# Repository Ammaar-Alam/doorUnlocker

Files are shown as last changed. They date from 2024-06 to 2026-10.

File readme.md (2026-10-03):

# Door Opener

A gearmotor, a printed spindle, and a length of fishing line turn a regular door handle into one you can open from your phone. The website shows the mechanism in 3D, with live controller status and parts you can explore.

[Open the website](https://door.ammaaralam.com) · [Watch the demo](https://youtube.com/shorts/K_ev5bF7mhw)

<a href="https://youtube.com/shorts/K_ev5bF7mhw">Watch the door opener in action on YouTube</a>

## The mechanism

The motor winds fishing line onto a custom spool to pull the handle down. Reversing the motor lets the handle return. An arbor knot anchors the line to the spindle; a round turn and half hitches attach it to the handle, secured under duct tape. The assembly mounts to the door with adhesive strips.

| Part | Purpose |
| --- | --- |
| Arduino Nano ESP32 | Receives commands over Wi-Fi and times each stroke |
| L298N driver | Controls motor direction and speed |
| BRINGSMART 24 V worm gearmotor | Winds and releases the line |
| Printed spindle and base | Gather the line and hold the assembly together |
| Mini breadboard and jumpers | Connect the controller and driver |
| Fishing line, duct tape, mounting strips | Attach the mechanism to the handle and door |

The [hardware guide](hardware/README.md) has part links and print files, including the original spindle STL. The [firmware guide](firmware/README.md) covers wiring, Arduino Cloud setup, uploading, and calibration.

## Try the interface

Use Node.js 22 and npm. No board or credentials are needed for the preview.

```sh
npm ci
npm run preview
```

Open [localhost:3107](http://localhost:3107). The preview uses a simulated controller and cannot move the real motor. Select a part to inspect it, drag to rotate the assembly, or use the door controls to see it move.

## Connect your own door

Set up the board using the [firmware guide](firmware/README.md), then configure the server:

```sh
cp .env.example .env
openssl rand -hex 32
```

Fill `.env` with your Arduino Cloud Thing ID, API credentials, door password, and the generated signing secret. `PROPERTY_ID` is the read-only `doorOpen` property; `COMMAND_PROPERTY_ID` is the writable `doorCommand` property.

```sh
npm test
npm start
```

Open [localhost:3000](http://localhost:3000). The website shares the controller’s reported state across connected browsers. See the [API guide](docs/API_GUIDE.md) for other clients and authentication settings.

Opening runs a calibrated 970 ms stroke; releasing runs for 620 ms. Each Open or Close received while idle runs a full stroke, including repeated commands in the same direction. Calibrate the timings for your own motor and handle.

There is no position sensor: status describes the controller’s state, not whether the physical door is shut. Start with the string released and watch the first powered cycle.

## iPhone app

The [iOS app](ios/README.md) provides the website interface on iOS 26+, Bluetooth reconnection, and live diagnostics, with native controls available as a fallback. Open `ios/DoorOpener.xcodeproj` in Xcode. It supports iPhone on iOS 18 or later.

## iPhone shortcut

In Shortcuts, send `POST /open`, wait five seconds, then send `POST /close`. Supply the door password with each request when authentication is required.

The phone owns the wait and the closing request. If that request does not arrive, the handle remains held. Older files in `shortcuts/` use the removed `/pulse` endpoint and must be updated before use.

[MIT license](LICENSE)

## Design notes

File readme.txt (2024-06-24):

Here's a detailed and comprehensive README file for your GitHub repository:

---

# Smart Dorm Door Control System

This repository contains the code, schematics, and documentation for a smart dorm room door control system. The system uses an Arduino Nano RP2040 Connect, a motor driver (L298N), and a DC motor to remotely open and close a dorm room door. The project leverages Arduino IoT Cloud for remote control via WiFi and Bluetooth Low Energy (BLE).

## Table of Contents

- [Introduction](#introduction)
- [Features](#features)
- [Components](#components)
- [Hardware Setup](#hardware-setup)
- [Software Setup](#software-setup)
- [Arduino Code](#arduino-code)
- [Web Interface](#web-interface)
- [Usage](#usage)
- [Troubleshooting](#troubleshooting)
- [Future Work](#future-work)
- [Acknowledgements](#acknowledgements)

## Introduction

This project was developed to remotely control the opening and closing of a dorm room door using a DC motor and a motor driver. The system is integrated with Arduino IoT Cloud, enabling remote control through a web interface or BLE. The project showcases how IoT can be utilized for smart home automation, specifically for controlling door locks.

## Features

- Remote door control via Arduino IoT Cloud
- BLE support for local control
- Real-time status updates of the door
- Visual feedback with LEDs
- Modern and sleek web interface

## Components

- Arduino Nano RP2040 Connect
- L298N Motor Driver
- 24V DC Motor
- Power Supply (12V and 24V)
- Push Buttons [OPTIONAL]
- LEDs (Red and Green) [OPTIONAL]
- Jumper Wires
- Breadboard
- Fishing Line

## Hardware Setup

1. **Power Supply:**
   - Connect the 24V power supply to the L298N motor driver.
   - Ensure the 5V jumper on the L298N is removed.
   - Use a DC-DC buck converter to step down 24V to 5V for the Arduino Nano RP2040 Connect.

2. **Motor Driver Connections:**
   - Connect the 24V DC motor to the OUT1 and OUT2 terminals of the L298N.
   - Connect IN1 and IN2 on the L298N to digital pins 2 and 3 on the Arduino.
   - Connect the ENA pin to digital pin 9 on the Arduino.
   - Connect the 5V pin on the Arduino to the 5V input on the L298N.

3. **[OPTIONAL] LEDs:**
   - Connect the red LED to a digital pin (e.g., pin 10) with a current-limiting resistor.
   - Connect the green LED to another digital pin (e.g., pin 11) with a current-limiting resistor.

4. **[OPTIONAL] Push Buttons:**
   - Connect one side of the push button to the 5V rail.
   - Connect the other side to a digital pin (e.g., pin 4) with a pull-down resistor to ground.

## Software Setup

1. **Arduino IDE:**
   - Install the Arduino IDE from [here](https://www.arduino.cc/en/software).
   - Install the necessary libraries: WiFiNINA, ArduinoIoTCloud, Arduino_ConnectionHandler.

2. **Arduino IoT Cloud:**
   - Create an account on [Arduino IoT Cloud](https://create.arduino.cc/iot).
   - Define a new device and link it to your Arduino Nano RP2040 Connect.
   - Create a property named `doorOpen` of type `boolean` with read/write permissions.

3. **Web Interface:**
   - The web interface is located in the `public` folder.
   - Update `script.js` to include your Arduino IoT Cloud credentials.

## Arduino Code

The Arduino code is responsible for controlling the motor, updating the door status, and handling BLE connections. The main code is in `door_control.ino` and the BLE-specific code in `ble_control.ino`.

### Example Code Snippet
```cpp
#include <WiFiNINA.h>
#include <ArduinoIoTCloud.h>
#include <Arduino_ConnectionHandler.h>

// Replace with your network credentials
const char SSID[] = "puvisitor";
const char PASS[] = ""; // No password for the network

// Arduino IoT Cloud credentials
const char THING_ID[] = "3420f1e7-f743-4d7d-91df-ea746d4f01e0"; // Replace with your Thing ID
const char DEVICE_ID[] = "0f91b9e4-a0db-48b7-8bfd-83ebc031e134"; // Replace with your Device ID

// Declare a property to sync with Arduino Cloud
bool doorOpen;

WiFiConnectionHandler ArduinoIoTPreferredConnection(SSID, PASS);

// Motor control pins
const int IN2 = 2;
const int IN3 = 3;

// LED pins
#define RED_LED 10
#define GREEN_LED 11

// Motor run duration in milliseconds
const unsigned long motorRunTime = 1000;

// Callback function to handle changes in doorOpen
void onDoorOpenChange() {
    Serial.print("Door state changed to: ");
    Serial.println(doorOpen ? "Open" : "Closed");

    if (doorOpen) {
        digitalWrite(IN2, HIGH);
        digitalWrite(IN3, LOW);
        digitalWrite(RED_LED, HIGH); // Turn on red LED
        digitalWrite(GREEN_LED, LOW);  // Turn off green LED
        delay(motorRunTime); // Run motor for specified duration
        digitalWrite(IN2, LOW);
        digitalWrite(IN3, LOW);
    } else {
        digitalWrite(IN2, LOW);
        digitalWrite(IN3, HIGH);
        digitalWrite(RED_LED, LOW);  // Turn off red LED
        digitalWrite(GREEN_LED, HIGH); // Turn on green LED
        delay(motorRunTime); // Run motor for specified duration
        digitalWrite(IN2, LOW);
        digitalWrite(IN3, LOW);
    }
}

void setup() {
    // Initialize motor control pins
    pinMode(IN2, OUTPUT);
    pinMode(IN3, OUTPUT);
    digitalWrite(IN2, LOW);
    digitalWrite(IN3, LOW);

    // Initialize LED pins
    pinMode(RED_LED, OUTPUT);
    pinMode(GREEN_LED, OUTPUT);
    digitalWrite(RED_LED, LOW);
    digitalWrite(GREEN_LED, HIGH); // Default to door closed

    Serial.begin(9600);

    // Connect to WiFi
    Serial.print("Attempting to connect to Network named: ");
    Serial.println(SSID);
    WiFi.begin(SSID);

    while (WiFi.status() != WL_CONNECTED) {
        delay(1000);
        Serial.print(".");
    }

    Serial.println();
    Serial.println("Connected to network");
    Serial.print("SSID: ");
    Serial.println(WiFi.SSID());
    Serial.print("IP Address: ");
    Serial.println(WiFi.localIP());
    Serial.print("Signal strength (RSSI):");
    Serial.print(WiFi.RSSI());
    Serial.println(" dBm");

    // Initialize Arduino IoT Cloud
    ArduinoCloud.begin(ArduinoIoTPreferredConnection);
    setDebugMessageLevel(2);
    ArduinoCloud.printDebugInfo();

    // Define Thing properties
    ArduinoCloud.addProperty(doorOpen, READWRITE, ON_CHANGE, onDoorOpenChange);
}

void loop() {
    ArduinoCloud.update();

    if (WiFi.status() != WL_CONNECTED) {
        Serial.println("Wi-Fi connection lost. Reconnecting...");
        while (WiFi.status() != WL_CONNECTED) {
            delay(1000);
            Serial.print(".");
        }
        Serial.println();
        Serial.println("Reconnected to network");
    }
}
```

## Web Interface

The web interface is built using HTML, CSS, and JavaScript.

### Example `index.html`
```html
<!doctype html>
<html>
<head>
    <title>Smart Dorm Control</title>
    <link rel="stylesheet" href="styles.css">
    <script src="script.js" defer></script>
</head>
<body>
    <header>
        <h1>Ammaar's Dorm Room Controls</h1>
    </header>
    <main>
        <section id="door-control">
            <h2>Door Status</h2>
            <label class="switch">
                <input type="checkbox" id="doorSwitch" onclick="toggleSwitch()">
                <span class="slider"></span>
            </label>
            <div id="doorStatus">
                <span id="statusClosed">Closed</span>
                <span id="statusOpen">Open</span>
            </div>
        </section>
        <section id="about">
            <h2>About This Project</h2>
            <p>This is a personal project I worked on over the summer...</p>
        </section>
        <section id="contact">
            <h2>Connect with Me</h2>
            <p><a href="#">GitHub</a> | <a href="#">LinkedIn</a> | <a href="#">Photography Portfolio</a></p>
        </section>
    </main>
    <footer>
        <p>&copy; 2024-25 Ammaar Alam. All rights reserved.</p>
    </footer>
</body>
</html>
```

## Usage

1. **Power On:**
   - Connect the power supply to the motor driver and Arduino.

Sure, let's continue to build the README file for your project. Here’s the rest of the detailed and comprehensive README file:

---

## Usage

1. **Power On:**
   - Connect the power supply to the motor driver and Arduino.
   - Ensure that the jumper settings on the L298N motor driver are correct. If using the ENA pin, ensure the jumper is removed and connected to the Arduino.

2. **Control via Web Interface:**
   - Open the web interface by navigating to the server's IP address or domain.
   - Use the toggle switch to open or close the door. The status will be updated in real-time.

3. **Control via Bluetooth:**
   - Pair your phone with the Arduino using a Bluetooth terminal app.
   - Send commands (`0` or `1`) to control the door.

## Troubleshooting

1. **WiFi Connectivity Issues:**
   - Ensure that the correct SSID and password are used in the Arduino sketch.
   - Check if the Arduino is within the range of the WiFi network.
   - Verify if the WiFi network allows connections from IoT devices.

2. **Motor Not Spinning:**
   - Check the connections between the motor driver and the motor.
   - Ensure that the power supply voltage matches the motor's requirement.
   - Verify if the ENA pin is connected and not bypassed.

3. **Arduino Not Responding:**
   - Make sure the Arduino is properly powered.
   - Check if the sketch is correctly uploaded to the Arduino.
   - Ensure the serial monitor is closed when not in use to avoid interference.

4. **BLE Connectivity Issues:**
   - Ensure the BLE service is correctly set up in the sketch.
   - Use a reliable BLE terminal app to connect and send commands.

## Future Work

- **Integration with More Sensors:**
  - Add sensors to detect door status more automatically.
  - Integrate other home automation features like lighting control.

- **Enhanced Security:**
  - Implement user authentication for the web interface.
  - Add encryption to BLE communications.

- **Mobile App:**
  - Develop a mobile app for easier control and monitoring.

## Acknowledgements

This project was inspired by various IoT and home automation projects. Special thanks to the Arduino community for the extensive documentation and support.

## License

This project is licensed under the MIT License - see the [LICENSE](LICENSE) file for details.

---

## Troubleshooting and Problems Encountered

### 1. **Arduino Getting Stuck on `Serial.begin`**
   - **Issue:** The Arduino would get stuck on `Serial.begin` when not connected to a computer.
   - **Solution:** Ensure the Arduino has a proper power source and is not relying on the serial connection for power.

### 2. **Determining Correct Jumper Settings on L298N**
   - **Issue:** The motor was not spinning due to incorrect jumper settings.
   - **Solution:** Refer to the [L298N Motor Driver Module documentation](https://components101.com/modules/l293n-motor-driver-module) for correct jumper settings.

### 3. **Power Supply Issues**
   - **Issue:** Ensuring the Arduino and motor driver could share a power supply without causing voltage issues.
   - **Solution:** Use a DC-DC buck converter to step down voltage where necessary, and ensure all components are rated for the supplied voltage.

### 4. **Connecting to Eduroam WiFi**
   - **Issue:** Connecting the Arduino to the complex Eduroam WiFi network.
   - **Solution:** Use WPA2 Enterprise settings and ensure the correct identity and credentials are used. Refer to [Eduroam setup guides](https://www.eduroam.org).

### 5. **Motor and Driver Compatibility**
   - **Issue:** Motor driver overheating or not working with the motor.
   - **Solution:** Ensure the motor and driver are compatible in terms of voltage and current ratings. Use proper heat sinks if necessary.

### 6. **Soldering VUSB Pads**
   - **Issue:** Enabling 5V output on Arduino Nano RP2040 Connect.
   - **Solution:** Solder the VUSB pads as shown in the Arduino documentation. If soldering tools are not available, seek help from someone experienced.

### 7. **Miscellaneous Hardware Issues**
   - **Issue:** Broken wires, loose connections, and improper use of breadboards.
   - **Solution:** Regularly inspect and replace damaged wires. Ensure all connections are secure and use proper wire stripping and connection techniques.

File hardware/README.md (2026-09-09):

# Print files

- [Optimized motor spindle](models/motor-spindle-final-optimized.stl): current spindle export
- [Bambu Studio project](models/motor-spindle-final-optimized.3mf): saved slicer project for that export
- [Base](models/base.stl) and [base with holes](models/base_holes.stl)
- [Driver caps](models/driverCaps.stl)

The original editable spindle model is retained in [source/](source/). It predates the optimized STL. Review material, orientation, supports, and printer selection in the 3MF before printing; saved slicer settings are specific to the original print setup.

## Parts

- [Motor](https://www.amazon.com/dp/B07F8T6KKD): BRINGSMART 24 V worm gearmotor
- [Arduino Nano ESP32 with headers](https://www.amazon.com/dp/B0C947BHK5)
- [L298N motor driver](https://www.amazon.com/dp/B07WS89781)
- [Mounting strips](https://a.co/d/3m5qMEm)

## String attachment

- **Spindle end:** use an **Arbor knot** to attach the string to the spindle
- **Handle end:** a **round turn and half hitches**, with duct tape wrapped over the knot

Check both knots and start with the string released before the first powered cycle.

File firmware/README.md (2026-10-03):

# Nano ESP32 firmware

Open `doorOpener/doorOpener.ino` in Arduino IDE or use Arduino CLI. This sketch targets the Arduino Nano ESP32, FQBN `arduino:esp32:nano_nora`.

## Wiring

| Nano pin | Connection |
| --- | --- |
| D2 | L298N IN1 |
| D3 | L298N IN2 |
| D9 | L298N ENA, with its enable jumper removed |
| GND | Common ground with the motor driver |

Power the motor driver from the motor's supply and power the Nano separately through USB or an appropriate regulated supply. Do not connect the 24 V motor supply to a Nano GPIO or 3.3 V pin.

## Arduino Cloud

Use these variables on the associated Thing:

| Variable | Type | Permission | Update |
| --- | --- | --- | --- |
| `doorOpen` | Boolean / Status | Read only | On change |
| `doorCommand` | Character String | Read and write | On change |
| `doorTelemetry` | Character String | Read only | On change |

The server uses the property IDs in `.env`. `thingProperties.h` contains this project's device login ID; change it when pairing a different board.

Copy `doorOpener/arduino_secrets.example.h` to `doorOpener/arduino_secrets.h`, then enter the device secret and WiFi settings. The real header is ignored by Git. Arduino Cloud sketch downloads omit secret values, so a downloaded header must be configured before uploading.

## Build and upload

Validated with Arduino ESP32 Boards `2.0.18-arduino.5` and ArduinoIoTCloud `2.10.0`:

```sh
arduino-cli core install arduino:esp32@2.0.18-arduino.5
arduino-cli lib install ArduinoIoTCloud@2.10.0
arduino-cli compile --fqbn arduino:esp32:nano_nora firmware/doorOpener
arduino-cli board list
```

Select the Nano's detected USB port in Arduino IDE to upload. If it does not enter upload mode, double-press RESET quickly. Disconnect the motor or string for the first upload and software check.

## Automatic OTA uploads

The GitHub `Checks` workflow uploads firmware through Arduino Cloud after tests pass on `main` when firmware or its deployment configuration changes. Pull requests only run checks. Run `Checks` manually on `main` to retry an update without another code change.

Configure these GitHub environment secrets in `door-unlocker`:

- `ARDUINO_CLOUD_CLIENT` and `ARDUINO_CLOUD_SECRET`: an Arduino Cloud API key
- `ARDUINO_SECRETS_HEADER`: the complete configured `arduino_secrets.h` file

The device ID comes from `thingProperties.h`. The board must be online, already running OTA-capable Arduino Cloud firmware, and have an OTA-enabled Cloud plan. The workflow compiles with the private device/Wi-Fi configuration and waits for the specific OTA job to succeed. Firmware binaries contain credentials and are not published as GitHub artifacts.

OTA reboots the board. Keep the handle released and avoid motor commands during an update. The first upload may require USB if the installed firmware does not support OTA. The GitHub job summary records the deployed commit and OTA ID; an accepted upload request alone is not completion. After an upload timeout, inspect that OTA ID before retrying.

Uploading a binary does not synchronize the Cloud editor's source files. GitHub is the firmware source of truth; the editor can still show an older sketch after a successful OTA upload.

## Bluetooth proximity

The board advertises as **Ammaar's Door Opener** and supports up to four simultaneous phone connections. Use the iOS app's Show pairing code and Connect door actions to pair without USB while the controller is online. USB Serial Monitor at 9600 baud remains a fallback for other BLE clients. Pairing uses authenticated encryption and saved Bluetooth bonds; later connections do not need the laptop. The board never requests security itself: the phone encrypts with its saved bond when it reads the protected identity. The ESP32 Bluetooth stack erases a bond whenever a board-initiated security request fails, including when the link drops mid-request at the edge of range. Unpaired or unauthenticated connections cannot operate the motor. Keep the board powered after unplugging USB.

Each connection requests a 30–45 ms interval, zero peripheral latency, and a six-second supervision timeout. The phone decides whether to accept these parameters. This allows brief radio interruptions before declaring a disconnection.

A known phone arms after at least **15 seconds continuously disconnected**. After reconnecting and authenticating, two fresh RSSI readings at or above **−65 dBm** within one second request an automatic opening. Weak readings between them are allowed; invalid or stale readings do not count. Sampling runs every 100 ms while an arrival is armed, so weak readings cannot delay the next sample beyond the confirmation window. After the arrival is consumed, sampling runs once per second below −80 dBm and every 100 ms at or above −80 dBm. These thresholds are in `ProximityController.h`.

Each remembered phone gets one automatic opening per arrival. Brief reconnects preserve an armed arrival but clear its pending reading; staying connected or fluctuations in RSSI cannot rearm it. The controller remembers up to four phone addresses resolved by the Bluetooth stack. Startup, newly seen phones, and replaced slots begin disarmed and need a connection followed by a 15-second absence. Arrival state is kept in RAM, so restarting the controller resets it.

An automatic opening completes the 970 ms stroke, holds with motor power off for **four seconds**, then releases for **620 ms**, regardless of subsequent RSSI or disconnection. Arrivals during an existing movement or while already open share that opening and do not repeat or extend it. Manual commands take precedence and cancel the automatic release; manual Open stays held until an explicit Close.

`doorTelemetry` reports a compact snapshot every 500 ms while phones are connected, on connection-count changes, and once per minute when none are connected. Each paired phone has a slot number, RSSI, and near flag (RSSI at or above −65 dBm). The reported RSSI is the strongest reading from the last one to two seconds; fading, body blocking, and Wi-Fi sharing the radio only pull individual readings down, often by 30 dB or more. Arrival detection still uses individual readings. Slot numbers can be reused for newly seen phones. A null RSSI indicates no valid current reading. The connected count includes phones still pairing. The existing Arduino Cloud MQTT subscription writes these snapshots to the server log with the prefix `Bluetooth RSSI:`. Network delays can reduce the observed update rate; motor decisions never wait for telemetry delivery.

Create the read-only `doorTelemetry` and `doorPairingCode` String properties with On change updates before deploying this firmware. Disable timeseries persistence for the pairing code; it is a credential, not diagnostic history. The firmware republishes its current PIN on Cloud synchronization, and the authenticated `/pairing-code` endpoint retrieves it on demand.

Disable Cloud timeseries persistence for `doorTelemetry` if the server journal is the intended history store. Only the latest outgoing snapshot is retained in a fixed 256-byte queue; old snapshots are replaced while the network is busy. The server drops diagnostic output if its log stream is backpressured. Pairing codes and phone addresses are not included in telemetry.

RSSI is not a distance or door-position sensor. A connection loss lasting 15 seconds can rearm a phone even inside the room. First pair with motor power disconnected, then test one supervised approach/departure cycle. Check operation with the phone pocketed, locked, and the BLE app in the background; the phone must maintain or re-establish the BLE connection for proximity to work. Initial opening still requires the full motor stroke after the signal threshold is confirmed.

## Timing and string adjustment

`DoorController.h` contains the motor power and timing calibration. Opening takes 970 ms and releasing takes 620 ms. A separate ESP32 task controls the motor, so WiFi and cloud calls cannot extend a powered stroke. Each stroke completes even if the network disconnects. A manual opening stays held until a Close command arrives; BLE arrivals use the four-second hold described above.

Each Open or Close received while idle runs a full stroke, regardless of the reported position. The controller completes a stroke before reversing so a partially wound string is not followed by a full release stroke. Force Open/Close also run a full stroke while idle and are ignored during movement.

Start with the string released. There is no encoder or position sensor, so firmware cannot determine string tension or its initial physical position after power loss. Test a single cycle while watching the mechanism before leaving it connected.

`npm test` includes a native C++ check of the calibrated timing, duplicate commands, early closing, and clock rollover.

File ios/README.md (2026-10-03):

# Door Opener for iOS

Open `DoorOpener.xcodeproj` in Xcode. Select your signing team and an available bundle identifier in Signing & Capabilities. The app supports iPhone on iOS 18 or later. Archive for an iOS device to distribute through TestFlight; increment the build number for subsequent uploads.

On iOS 26 and later, the Door tab displays the actual website using Apple’s SwiftUI WebView, including its 3D mechanism, typography, controls, and live status. It does not use the former custom UIViewRepresentable wrapper. The website and native tabs share an HTTP-only login cookie through WebKit’s cookie store, with migration of the existing native session. Native controls remain available on iOS 18–25 and through Connection → Display → Simple controls. This provides a fallback for browser or OS problems. Real-device interaction testing is still required after changing the web presentation.

The website and native controls wait for a fresh target-state report before clearing a command, with a bounded confirmation timeout. Status describes the controller, not a position sensor. Repeated same-state strokes may remain unconfirmed because the boolean report does not change. Neither interface automatically resends an uncertain command.

In Connection, sign in and tap Show pairing code before Connect door. The code comes from the online controller through the authenticated server, so USB is not needed for normal pairing. The system accessory picker handles setup. Existing saved accessories migrate into AccessorySetupKit on the first Connect door action. Reconnect restarts the connection while preserving pairing; Forget door asks iOS to remove the managed accessory. If pairing information is lost, forget and set up the door again from this screen. The firmware protects the identity read with authenticated encryption, so the app waits for pairing before showing Connected.

The pairing-code feature requires the read-only String Cloud property `doorPairingCode` with On change updates and persistence disabled, plus the matching firmware and server deployment. The PIN is read only on request, is not added to diagnostics or ordinary server logs, and is cleared from the screen when hidden or backgrounded. USB Serial at 9600 baud remains an offline fallback. The code changes when the controller restarts.

Do not force-quit the app if you want background reconnection. Bluetooth must stay enabled. iOS controls connection scheduling; instant reconnection cannot be guaranteed. Verify a locked-phone walk out of range and back on a real iPhone. The simulator cannot validate BLE pairing or proximity actuation.

Logs shows up to 200 recent phone connection events in memory and the server's latest Arduino telemetry. Deploy the accompanying server change to enable `/api/diagnostics`. That endpoint requires a valid login at all times, serves one cached MQTT snapshot without extra Arduino requests, and stores no additional history. The app polls every 500 ms only while Logs is visible and active, backing off on errors. The timestamp shows how old a report is. The server's existing journal retention is unchanged. Phone identifiers in Arduino reports are connection slots, not stable phone identities.

The motor release and both animations take 620 ms; opening takes 970 ms. BLE RSSI cannot distinguish which side of a door a phone is on.

Checks (the native requests are intercepted and do not actuate hardware):

```sh
bash scripts/check-ios.sh
xcodebuild -project ios/DoorOpener.xcodeproj -scheme DoorOpener -sdk iphonesimulator -configuration Debug CODE_SIGNING_ALLOWED=NO build
```

## Xcode Cloud

The shared `DoorOpener` scheme is checked in. Configure cloud start conditions in Xcode or App Store Connect: pull requests targeting `main` and changes to `main`. Select a stable Xcode version, `ios/DoorOpener.xcodeproj`, and the `DoorOpener` scheme. A Build action validates compilation; TestFlight delivery requires an Archive action and a TestFlight post-action. Cloud workflows are managed by Apple, not GitHub Actions YAML.

The Xcode Cloud post-clone script runs the native command and Bluetooth recovery checks before building.

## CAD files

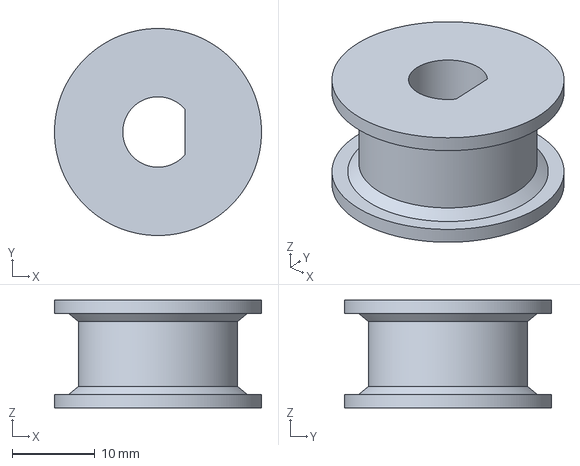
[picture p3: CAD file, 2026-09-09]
hardware/models/motor-spindle-final-optimized.3mf
25.0 x 25.0 x 13.0 mm

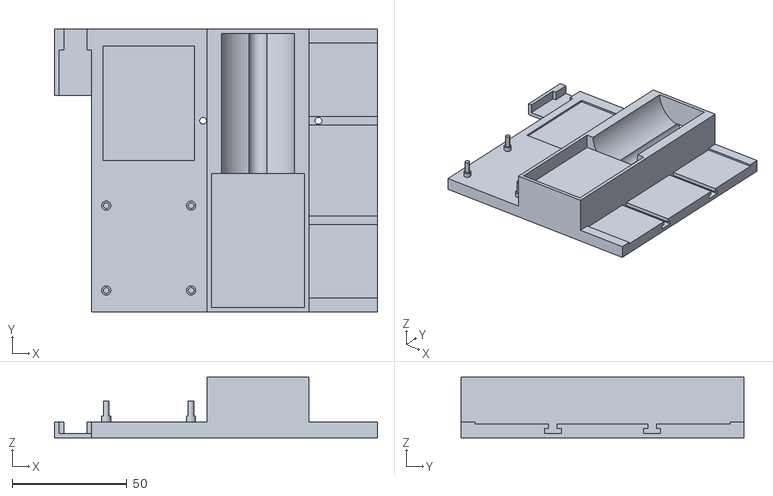
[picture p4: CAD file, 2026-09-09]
hardware/models/base_holes.stl
140.7 x 123.2 x 26.5

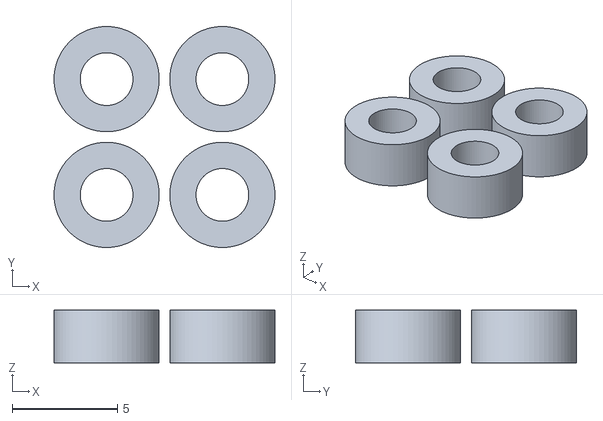
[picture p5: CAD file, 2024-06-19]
hardware/models/driverCaps.stl
10.5 x 10.5 x 2.50

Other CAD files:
hardware/models/base.stl
WIP Files/Project Handle 2/parts/motor-spindle.blend
hardware/models/motor-spindle-final-optimized.stl
hardware/source/motor-spindle-original.blend

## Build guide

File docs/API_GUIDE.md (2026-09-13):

# API

Routes are relative to your server (`http://localhost:3000` when running locally). The same routes are available under `/api` for existing clients. Responses use JSON and are not cached.

## Authentication

During protected hours, supply the password in the JSON request body, or use `POST /login` with a `password` string to obtain a token. A browser receives an HTTP-only cookie; other clients can send the returned token in `Authorization: Bearer …`. Login always checks the password, including during public hours. Tokens expire after 24 hours by default.

`AUTH_REQUIRED=scheduled` protects midnight through 7:59:59 a.m. in `America/New_York`. `true` always requires authentication; `false` allows public control. The schedule is evaluated in the server on every request and survives restarts without a scheduled job.

## Routes

| Method | Path | Purpose |
| --- | --- | --- |
| GET | `/auth-status` | Returns `authRequired` and `authenticated` |
| POST | `/login` | Checks `password`, sets a cookie, and returns `token` |
| GET | `/status` | Returns `doorOpen`, `online`, and `updatedAt` |
| GET | `/events` | Streams the same status using server-sent events |
| GET | `/diagnostics` | Returns the latest RSSI snapshot; login always required |
| GET | `/pairing-code` | Returns the online controller’s current six-digit PIN; login always required |
| POST | `/open` | Opens the handle without a timer |
| POST | `/close` | Releases the handle |
| POST | `/force-open` | Runs another opening stroke while idle |
| POST | `/force-close` | Runs another closing stroke while idle |
| POST | `/command` | Accepts `command` with one of the four action names above |
| POST | `/emergency-close` | Alias for normal Close |
| POST | `/ring-doorbell` | Sends optional `message` text when notification delivery is configured |

Successful commands return `{"ok":true,"command":"open","message":"Command sent"}`. This confirms Arduino Cloud accepted the request; it is not a physical-position acknowledgement. Read `/status` or `/events` for the controller's reported state. When offline, `doorOpen` is `null`, not a stale open or closed value.

The Arduino ignores expired commands and commands retained from a previous connection. Each Open or Close received while idle runs a full stroke, even when the controller already reports that position. A Close received during the opening stroke completes that calibrated stroke before reversing; a Close after opening starts releasing immediately. Force commands are ignored while a stroke is already running.

Clients own any wait between Open and Close. The `/pulse` endpoint is no longer supported; replace it with separate Open and Close requests. If Close never arrives, the handle remains held.

The pairing-code endpoint returns a `code` string. It requires a valid login cookie or Bearer token even during public hours. The controller must publish the read-only `doorPairingCode` Cloud property. PINs are not included in status, SSE, or RSSI logs.

## Errors

Errors return `{"ok":false,"message":"…"}` with a suitable HTTP status:

- `400`: invalid command, body, or JSON
- `401`: login required or invalid password
- `409`: another request is currently publishing a command
- `503`: controller offline or configuration missing
- `502`: Arduino or notification service failure, including a timeout

Do not automatically retry a command after a timeout: it may already have reached the controller. Check the live state before issuing another action.

The server retries explicit Arduino HTTP 429 responses up to twice within the request timeout, honoring `Retry-After` when provided. Retries keep the same command ID and expiry. Timeouts and other ambiguous failures are not retried. Logs identify failed commands and rate-limited endpoints, including this server's request count in the preceding second.

## Temporary authentication override

`POST /admin/set-auth-required` requires `X-Admin-Token` matching `ADMIN_TOKEN`. Send `enabled: true` to protect access, `false` to allow public control, or `null` to restore the configured schedule. This override lasts until it is cleared or the server restarts. Use `AUTH_REQUIRED=true` in the service configuration for an override that must survive restarts.

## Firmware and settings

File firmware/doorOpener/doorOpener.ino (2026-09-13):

#include "thingProperties.h"
#include "DoorController.h"
#include "BluetoothProximity.h"
#include <stdlib.h>
#include <atomic>
#include <freertos/FreeRTOS.h>
#include <freertos/queue.h>
#include <freertos/task.h>

const int IN1 = 2;
const int IN2 = 3;
const int ENA = 9;
#define RED_LED LED_GREEN
#define GREEN_LED LED_RED

QueueHandle_t commands;
std::atomic<bool> reportedOpen{false};
bool cloudSynced = false;
String lastCommand;

void onCloudSync() {
  lastCommand = doorCommand;
  doorOpen = reportedOpen.load();
  doorPairingCode = String(BluetoothProximity::passkey);
  cloudSynced = true;
}

void onCloudDisconnect() {
  cloudSynced = false;
}

// motor timing runs independently of cloud and WiFi calls
void motorTask(void *) {
  DoorController motor;
  int direction = 0;
  while (true) {
    DoorAction action;
    if (xQueueReceive(commands, &action, 0) == pdTRUE) motor.command(action, millis());
    motor.update(millis());
    const int nextDirection = !motor.moving ? 0 : motor.opening ? 1 : -1;
    if (nextDirection != direction) {
      analogWrite(ENA, 0);
      digitalWrite(IN1, nextDirection == 1 ? HIGH : LOW);
      digitalWrite(IN2, nextDirection == -1 ? HIGH : LOW);
      direction = nextDirection;
      if (Serial) Serial.printf("%lu motor %s\n", millis(), direction > 0 ? "opening" : direction < 0 ? "closing" : "stopped");
    }
    analogWrite(ENA, motor.pwm);
    reportedOpen.store(motor.open);
    digitalWrite(RED_LED, motor.open ? HIGH : LOW);
    digitalWrite(GREEN_LED, motor.open ? LOW : HIGH);
    vTaskDelay(1);
  }
}

void setup() {
  pinMode(IN1, OUTPUT);
  pinMode(IN2, OUTPUT);
  pinMode(ENA, OUTPUT);
  digitalWrite(IN1, LOW);
  digitalWrite(IN2, LOW);
  analogWrite(ENA, 0);
  pinMode(RED_LED, OUTPUT);
  pinMode(GREEN_LED, OUTPUT);
  digitalWrite(RED_LED, LOW);
  digitalWrite(GREEN_LED, HIGH);
  Serial.begin(9600);
  commands = xQueueCreate(1, sizeof(DoorAction));
  if (!commands || xTaskCreate(motorTask, "door-motor", 4096, nullptr, 2, nullptr) != pdPASS) {
    Serial.println("Motor controller could not start");
    while (true) delay(1000);
  }
  BluetoothProximity::begin(commands);
  initProperties();
  ArduinoCloud.addCallback(ArduinoIoTCloudEvent::SYNC, onCloudSync);
  ArduinoCloud.addCallback(ArduinoIoTCloudEvent::DISCONNECT, onCloudDisconnect);
  ArduinoCloud.begin(ArduinoIoTPreferredConnection);
}

void loop() {
  BluetoothProximity::readTelemetry(doorTelemetry);
  ArduinoCloud.update();
  doorOpen = reportedOpen.load();
}

void onDoorCommandChange() {
  if (!cloudSynced || doorCommand == lastCommand || doorCommand.length() > 100) return;
  lastCommand = doorCommand;
  const int separator = doorCommand.indexOf(':');
  const int end = doorCommand.indexOf(':', separator + 1);
  if (separator <= 0 || end <= separator + 1) return;
  const String expiryText = doorCommand.substring(separator + 1, end);
  char *tail;
  const unsigned long expiresAt = strtoul(expiryText.c_str(), &tail, 10);
  const unsigned long now = ArduinoCloud.getInternalTime();
  if (*tail || !now || expiresAt < now || expiresAt - now > 30) return;
  const String action = doorCommand.substring(0, separator);
  DoorAction command;
  if (action == "open") command = DoorAction::Open;
  else if (action == "close") command = DoorAction::Close;
  else if (action == "force-open") command = DoorAction::ForceOpen;
  else if (action == "force-close") command = DoorAction::ForceClose;
  else return;
  if (Serial) Serial.printf("%lu command %s\n", millis(), action.c_str());
  xQueueOverwrite(commands, &command);
}

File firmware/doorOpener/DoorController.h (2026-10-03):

#pragma once
#include <stdint.h>

// calibrated for the existing motor and string travel
constexpr int PWM_OPEN_PRETENSION = 110;
constexpr int PWM_OPEN_STAGE1 = 170;
constexpr int PWM_OPEN_PEAK = 185;
constexpr uint32_t OPEN_PRET_MS = 70;
constexpr uint32_t OPEN_RAMP1_MS = 120;
constexpr uint32_t OPEN_RAMP2_MS = 60;
constexpr uint32_t OPEN_CRUISE_MS = 600;
constexpr uint32_t OPEN_SOFT_STOP_MS = 120;
constexpr int PWM_CLOSE_TARGET = 100;
constexpr uint32_t CLOSE_RAMP_UP_MS = 110;
constexpr uint32_t CLOSE_HOLD_MS = 400;
constexpr uint32_t CLOSE_RAMP_DOWN_MS = 110;

enum class DoorAction { Open, Close, ForceOpen, ForceClose, ProximityOpen };

struct DoorController {
  bool open = false;
  bool moving = false;
  bool opening = false;
  int pwm = 0;

  void command(DoorAction action, uint32_t now) {
    const bool force = action == DoorAction::ForceOpen || action == DoorAction::ForceClose;
    const bool wantOpen = action != DoorAction::Close && action != DoorAction::ForceClose;
    if (force && moving) return;
    if (action == DoorAction::ProximityOpen) {
      // arrivals share an existing cycle and never override manual movement
      if (moving || open) return;
      automaticRelease = true;
    } else {
      automaticRelease = false;
    }
    requestedOpen = wantOpen;
    if (!moving) start(wantOpen, now);
  }

  void update(uint32_t now) {
    if (moving) {
      const uint32_t elapsed = now - startedAt;
      const uint32_t duration = opening
        ? OPEN_PRET_MS + OPEN_RAMP1_MS + OPEN_RAMP2_MS + OPEN_CRUISE_MS + OPEN_SOFT_STOP_MS
        : CLOSE_RAMP_UP_MS + CLOSE_HOLD_MS + CLOSE_RAMP_DOWN_MS;
      if (elapsed >= duration) {
        pwm = 0;
        moving = false;
        open = opening;
        if (open && automaticRelease) heldAt = now;
        // complete a stroke before reversing to preserve calibrated string travel
        if (requestedOpen != open) start(requestedOpen, now);
      } else {
        pwm = profile(elapsed);
      }
    }
    if (automaticRelease && !moving && open && uint32_t(now - heldAt) >= 4000) {
      automaticRelease = false;
      requestedOpen = false;
      start(false, now);
    }
  }

private:
  bool requestedOpen = false;
  bool automaticRelease = false;
  uint32_t heldAt = 0;
  uint32_t startedAt = 0;

  void start(bool wantOpen, uint32_t now) {
    moving = true;
    opening = wantOpen;
    startedAt = now;
    pwm = 0;
  }

  static int ramp(int from, int to, uint32_t elapsed, uint32_t duration) {
    if (!duration) return to;
    const float t = float(elapsed) / float(duration);
    const float value = from + (to - from) * t * t * (3 - 2 * t);
    return int(value + 0.5f);
  }

  int profile(uint32_t elapsed) const {
    if (opening) {
      if (elapsed < OPEN_PRET_MS) return ramp(0, PWM_OPEN_PRETENSION, elapsed, OPEN_PRET_MS);
      elapsed -= OPEN_PRET_MS;
      if (elapsed < OPEN_RAMP1_MS) return ramp(PWM_OPEN_PRETENSION, PWM_OPEN_STAGE1, elapsed, OPEN_RAMP1_MS);
      elapsed -= OPEN_RAMP1_MS;
      if (elapsed < OPEN_RAMP2_MS) return ramp(PWM_OPEN_STAGE1, PWM_OPEN_PEAK, elapsed, OPEN_RAMP2_MS);
      elapsed -= OPEN_RAMP2_MS;
      if (elapsed < OPEN_CRUISE_MS) return PWM_OPEN_PEAK;
      return ramp(PWM_OPEN_PEAK, 0, elapsed - OPEN_CRUISE_MS, OPEN_SOFT_STOP_MS);
    }
    if (elapsed < CLOSE_RAMP_UP_MS) return ramp(0, PWM_CLOSE_TARGET, elapsed, CLOSE_RAMP_UP_MS);
    elapsed -= CLOSE_RAMP_UP_MS;
    if (elapsed < CLOSE_HOLD_MS) return PWM_CLOSE_TARGET;
    return ramp(PWM_CLOSE_TARGET, 0, elapsed - CLOSE_HOLD_MS, CLOSE_RAMP_DOWN_MS);
  }
};

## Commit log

2024-06-20 updating button styling
2024-06-20 changing motor spin functionality
2024-06-21 changing motor time to be shorter
    [doorOpener.ino]
2024-06-21 updating for string approach
    [extended_slider.blend, extended_slider.stl, motor-spindle.blend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]
2024-06-22 updating timings
    [untitled.blend]
2024-06-22 fixing last minute updates
    [doorOpener.ino]
2024-06-24 updating thing ID to new esp board
2024-06-25 adding emergency close/unwind button
2024-06-25 updating button
2024-06-26 cleaning up files
    [extended_slider.blend, extended_slider.stl, handleJoint.stl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]
2024-06-27 adding keepAlive function to prevent cloud low-activity
    [doorOpener.ino]
2024-07-15 updating .ignore
    [base.stl, driverCaps.stl, gear.stl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]
2024-07-16 updating arduino code
2024-09-19 stronger string can support more torque
2024-09-19 fine-tuning motor speed
2024-12-08 updating app theme and button name
2025-02-19 adding dismiss button to login modal on iphone app
2025-02-19 adding dismiss button to contentview modal
2025-03-14 updating arduino sketches
2025-08-10 adding supression window to fix contradictory reads from arduino cloud
2025-08-26 switching login/doorbell div locations
2025-09-01 finetuning delays + swapping manual button colours
2025-09-01 adjusting motor open speed for new dorm door + finetuning cloud timeout
2026-09-09 fix(door): restore reliable control and clean up the project
    [base.stl, base_holes.stl, driverCaps.stl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]
2026-09-09 fix(door): preserve pulse when force close is ignored
    [DoorController.h, door-controller.cpp]
2026-09-09 feat(web): add interactive door mechanism view
    [gear.stl]
2026-09-12 fix(controller): shorten release stroke by 250 ms
    [DoorController.h, door-controller.cpp]
2026-09-12 feat(firmware): deploy main sketch changes over Arduino Cloud OTA
2026-09-12 fix(controller): restore repeat strokes and handle Arduino rate limits
    [DoorController.h, door-controller.cpp]
2026-09-13 fix(bluetooth): gate pairing read and allow forgetting a door
    [BluetoothProximity.h]
2026-09-13 fix(ios): use native controls and recover Bluetooth pairing
    [DoorController.h, door-controller.cpp]
2026-09-13 feat(bluetooth): manage system pairing and show authenticated PIN
2026-09-13 fix(bluetooth): remember arrivals only after authentication
    [BluetoothProximity.h, door-controller.cpp]
2026-09-29 fix(bluetooth): keep phone bonds across dropped links
    The Arduino BLE library sent a security request on every connection, and
    ESP-IDF 4.4 erases the bond whenever that request fails, including when the
    link drops before encryption completes. Walking out of range therefore wiped
    the phone's pairing and iOS reported lost pairing information on return.
    Phones now encrypt with their saved bond when reading the protected identity.
    Also:
    - report the recent RSSI peak so fades and Wi-Fi sharing no longer swing
    diagnostics between -40 and -100 dBm at the door
    - request a six-second supervision timeout and poll every 100 ms while an
    arrival is armed
    - lengthen the release stroke 1.25x to 688 ms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
    [BluetoothProximity.h, DoorController.h, door-controller.cpp]
2026-10-03 fix(controller): shorten release stroke to 620 ms
    The 688 ms release ran slightly long. Scale it to 620 ms (110 ms ramps,
    400 ms hold) and match the web and iOS animations.
    [DoorController.h, door-controller.cpp]
